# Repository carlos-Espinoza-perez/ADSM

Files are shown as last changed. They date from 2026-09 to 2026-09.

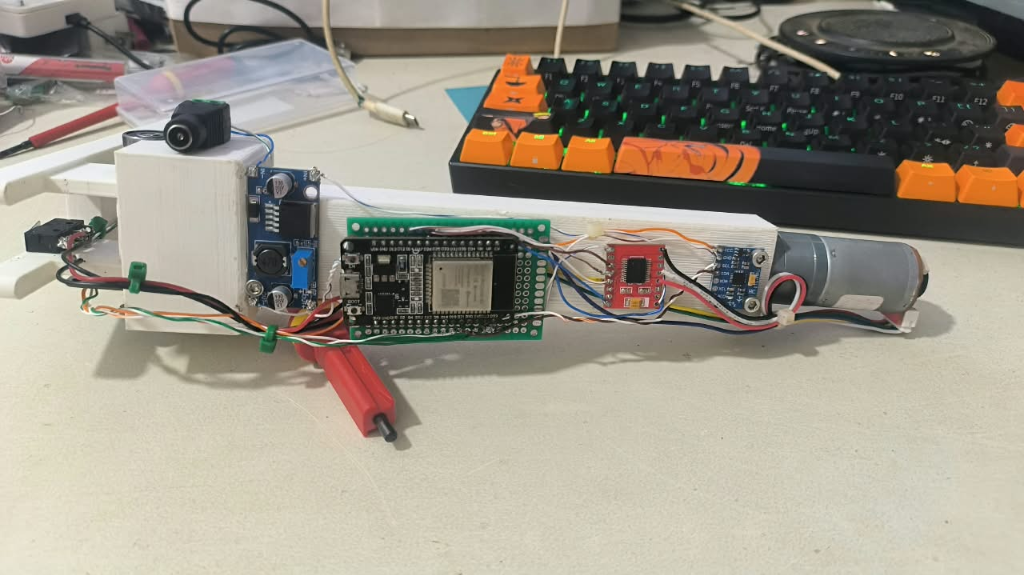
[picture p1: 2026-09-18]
02_Sistema_Electronico/07_Pruebas/Evidencias/01_Montaje_Fisico_Electronica_Columna_Lateral.png

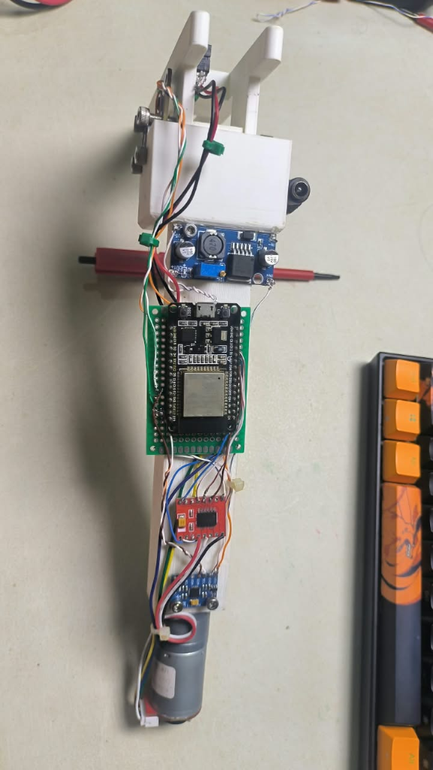
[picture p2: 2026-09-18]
02_Sistema_Electronico/03_Conexionado/Foto_Montaje_Real_Cableado_Prototipo.png

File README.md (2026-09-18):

# Prototipo Escalado de Tobillo Protésico Activo

Repositorio técnico correspondiente al análisis, diseño e implementación del prototipo mecatrónico de tobillo protésico activo de 1 Grado de Libertad (GDL) sagital, orientado al ajuste angular automático para asistencia a la marcha.

---

## Arquitectura General del Sistema

El sistema integra diseño mecánico paramétrico, acondicionamiento y distribución electrónica de potencia, y control embebido en tiempo real para el seguimiento de trayectorias angulares:

```
                      +-----------------------------+
                      |   Supervisión & Telemetría  |
                      |    (Node-RED / MQTT / WiFi) |
                      +--------------+--------------+
                                     |
                                     v
+------------------+     +--------------------+     +-------------------+
|     Sensores     |     |   Microcontrolador |     |      Actuación    |
| - AS5600 (I2C)   | --> |   ESP32-WROOM-32D  | --> | - Driver TB6612   |
| - MPU6050 (I2C)  |     |   Control PID 1 GDL|     | - Motor GA25-370  |
| - Celdas HX711   |     +--------------------+     | - Husillo M8      |
+------------------+                                +-------------------+
```

---

## Estructura de Subsistemas

El repositorio está organizado en tres subsistemas de ingeniería:

### 1. `01_Sistema_Mecanico`
Contiene la definición geométrica, analítica y dimensional del mecanismo de transmisión y soporte estructural:
- **`Calculos/`**: Memoria de cálculo cinemático, dimensionamiento de esfuerzos y verificación de pares de torsión.
- **`Modelos_CAD/`**: Archivos paramétricos de diseño en Autodesk Fusion 360 (`.f3d`), modelos exportados para manufactura (`.step`, `.stl`) y ensambles de referencia en SolidWorks.
- **`Planos/`**: Planos técnicos dimensionales normalizados en formato PDF, incluyendo vistas ortogonales, cortes y detalles de tolerancias para fabricación.
- **`Simulaciones/`**: Reporte técnico de barrido cinemático, análisis de desplazamientos y comprobación geométrica del rango angular ($\pm 15^\circ$).
- **`Evidencias/`**: Vistas de despiece, ensambles y capturas de verificación de ensamble.

### 2. `02_Sistema_Electronico`
Comprende el acondicionamiento eléctrico, potencia y esquemas de conexión:
- **`01_Arquitectura/`**: Diagramas de bloques del sistema electrónico y flujo de señales.
- **`02_Esquematico_Electrico/`**: Esquemas de conexionado general, reguladores y protecciones.
- **`03_Conexionado/`**: Diagrama de cableado punto a punto y tabla de conexionado.
- **`04_Alimentacion/`**: Dimensionamiento de consumo energético, baterías y distribución de líneas de 12V, 5V y 3.3V.
- **`05_Componentes/`**: Lista de materiales (BOM) y hojas de datos (*datasheets*) de componentes críticos.
- **`06_Control/`**: Asignación de pines (GPIO), modelos matemáticos en MATLAB/Simulink y rutinas de calibración.
- **`07_Pruebas/`**: Estructura para protocolos de prueba de continuidad, consumo y niveles lógicos.

### 3. `03_Sistema_Computacional`
Implementa el control en lazo cerrado, adquisición sensorial y telemetría:
- **`Firmware/`**: Código fuente modular para ESP32 (`codigo_final.ino`), incorporando el algoritmo de control PID, filtros digitales y pruebas unitarias de periféricos.
- **`Configuracion/`**: Parámetros de calibración angular persistentes (NVS) y mapa de tópicos MQTT.
- **`Interfaz/`**: Flujo para Node-RED y paneles de control telemétrico para monitoreo en tiempo real.
- **`Evidencias/`**: Registros de curvas de seguimiento angular, depuración de transitorios y calibración en banco.

---

## Especificaciones Técnicas

| Parámetro | Valor Nominal | Unidad |
|---|---|---|
| Grados de Libertad (GDL) | 1 (Sagital: flexión dorsal / plantar) | - |
| Rango Angular de Trabajo | $\pm 15.0$ | Grados ($^\circ$) |
| Mecanismo de Transmisión | Husillo métrico M8 con acople directo | Paso $1.25\text{ mm/rev}$ |
| Actuador Principal | GA25-370 (12 VDC, caja reductora) | Par nominal $\ge 0.15\text{ N}\cdot\text{m}$ |
| Sensor de Posición Angular | AS5600 magnético absoluto (I2C) | Resolución 12 bits ($0.088^\circ$) |
| Unidad de Procesamiento | ESP32 Dual Core @ 240 MHz | 520 KB SRAM |
| Protocolo de Telemetría | MQTT sobre red Wi-Fi (2.4 GHz) | JSON payload |

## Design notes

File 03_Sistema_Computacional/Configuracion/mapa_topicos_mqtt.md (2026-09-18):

# Protocolo de Comunicación y Mapa de Tópicos MQTT

La comunicación entre el microcontrolador ESP32 y el panel de supervisión (Node-RED) se realiza bajo el protocolo MQTT (puerto estándar 1883).

---

## Parámetros de Red

- **Client ID ESP32**: `tobilloESP32`
- **Puerto**: `1883`
- **Reconexión automática**: Cada 5000 ms ante pérdida de enlace.
- **Tamaño de buffer MQTT**: 2560 bytes.
- **Configuración de IP de Broker**: Asignable dinámicamente mediante el portal cautivo WiFiManager (pulsador BOOT en GPIO 0 por > 3 s).

---

## Tabla Oficial de Tópicos (Firmware v6)

Mapeo de tópicos MQTT sincronizado con las constantes `#define TOPIC_*` de `codigo_final.ino`:

| Tópico MQTT | Dirección | Tipo | Descripción | Formato / Ejemplo |
|---|:---:|:---:|---|---|
| `tobillo/estado` | ESP32 → Node-RED | LWT / Estado | Estado de conexión del dispositivo y mensaje Last Will and Testament. | `"conectado"` / `"desconectado"` |
| `tobillo/comando` | Node-RED → ESP32 | Control | Consignas operativas, reinicio, selección de modo o calibración NVS. | `"caminar:15.0"`, `"calibrar"`, `"histeresis"`, `"fuzzy"` |
| `tobillo/terreno` | Bidireccional | Datos | Inyección de ángulo de inclinación de terreno o reporte de clase estimada por el clasificador activo. | Valor numérico en grados (ej: `5.0`, `-10.0`) |
| `tobillo/telemetria` | ESP32 → Node-RED | Telemetría | Paquete JSON en tiempo real con ángulo real, setpoint, PWM aplicado y estado de switches. | `{"ang": 4.8, "sp": 5.0, "pwm": 120, "swT": 1, "swP": 0}` |
| `tobillo/ciclo` | ESP32 → Node-RED | Marcha | Subfase actual del ciclo de marcha y porcentaje de progresión del paso. | `{"fase": "APOYO_PLANO", "pct": 35.0}` |
| `tobillo/paso` | ESP32 → Node-RED | Eventos | Contador de pasos completados e indicador de cambio de estado de apoyo. | `{"paso": 42, "cadencia_spm": 54.0}` |
| `tobillo/log` | ESP32 → Node-RED | Diagnóstico | Espejo de la consola serial para monitoreo remoto y depuración de eventos críticos. | Texto estructurado / Alarmas (ej: `Slip_Alarm`) |

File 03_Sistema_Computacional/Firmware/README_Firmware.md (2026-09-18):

# Firmware del Prototipo de Tobillo Protésico Activo

El firmware del sistema se ejecuta sobre un microcontrolador **ESP32-WROOM-32 DevKit v1**. Administra la adquisición sensorial de marcha, el control de lazo cerrado del motorreductor sagital, la máquina de estados de las fases de apoyo/balanceo y la comunicación bidireccional mediante telemetría MQTT y consola serie.

---

## Estructura de Códigos

1. **`codigo_final/codigo_final.ino`**: Firmware integral operativo del prototipo.
   - Control de posición angular por odometría de pulsos de encoder con tabla de 5 puntos e interpolación lineal almacenada en memoria NVS.
   - Verificación cruzada contra el encoder magnético absoluto AS5600 montado en el eje articular (detección de *Slip Alarm*).
   - Detección de contacto de apoyo mediante microswitches de talón y punta con filtro de antirrebote (*debounce*) de 35 ms.
   - Estimación de inclinación mediante MPU-6050 por lectura directa de registros I2C a 400 kHz.
   - Servidor cautivo WiFiManager para aprovisionamiento dinámico de red y configuración del broker MQTT en campo.
   - Publicación de telemetría y suscripción a consignas remotas.

2. **`Pruebas_Unitarias/`**: Códigos individuales de validación de hardware en banco de laboratorio.
   - `i2c_scanner.ino`: Verificación de direcciones en bus I2C compartido (MPU-6050 en `0x68`, AS5600 en `0x36`).
   - `prueba_motor.ino`: Comprobación de sentido de giro y polarización del driver TB6612FNG con canales en paralelo.
   - `prueba_velocidad_motor.ino`: Barrido de PWM para determinar zona muerta mecánica (arranque mínimo a PWM ≈ 65) y conteo de encoder.
   - `prueba_todos_sensores.ino`: Comprobación conjunta de lectura simultánea en bus I2C y entradas digitales.
   - `prueba_hx711_talon.ino`: Código instrumental previo de caracterización de fuerza en banco de ensayos.

---

## Mapeo Oficial de Pines (ESP32-WROOM-32)

Mapeo rigurosamente estandarizado y verificado contra `codigo_final.ino`, el plano esquemático `Esquematico_Principal.pdf` y la tabla maestra de GPIO:

| Pin ESP32 | Nombre Firmware | Tipo I/O | Dispositivo Destino | Nivel Lógico | Polarización / Función |
|:---:|:---:|:---:|:---:|:---:|:---|
| **GPIO 0** | `BOTON_RESET` | Entrada Digital | Pulsador BOOT en placa | 3.3 V | Pull-up interna. Reset de WiFi y NVS al pulsar > 3 s |
| **GPIO 14** | `PIN_STBY` | Salida Digital | TB6612FNG (Pin STBY) | 3.3 V | Conexión directa. HIGH = Habilitado, LOW = Standby |
| **GPIO 21** | `SDA_PIN` | I2C Bidireccional | Bus I2C compartido | 3.3 V | Pull-up en módulos. SDA para MPU-6050 (`0x68`) y AS5600 (`0x36`) |
| **GPIO 22** | `SCL_PIN` | I2C Salida Reloj | Bus I2C compartido | 3.3 V | Pull-up en módulos. SCL a 400 kHz |
| **GPIO 25** | `PIN_AIN1` | Salida Digital | TB6612FNG (AIN1 + BIN1) | 3.3 V | Conexión directa. Dirección A (canales A y B en paralelo) |
| **GPIO 26** | `PIN_AIN2` | Salida Digital | TB6612FNG (AIN2 + BIN2) | 3.3 V | Conexión directa. Dirección B (canales A y B en paralelo) |
| **GPIO 27** | `PIN_PWM` | Salida PWM | TB6612FNG (PWMA + PWMB) | 3.3 V | Modulación LEDC a 20 kHz, resolución 8 bits (duty 0-255) |
| **GPIO 32** | `PIN_TALON` | Entrada Digital | Microswitch Talón | 3.3 V | Pull-up interna. Detección de contacto de talón (cierre a GND) |
| **GPIO 33** | `PIN_PUNTA` | Entrada Digital | Microswitch Punta | 3.3 V | Pull-up interna. Detección de apoyo de antepié (cierre a GND) |
| **GPIO 34** | `PIN_ENC_A` | Entrada Interrupción| Encoder GA25-370 Canal A | 3.3 V | **Pull-up externa de 10 kΩ a 3.3V** (pin de entrada pura) |
| **GPIO 35** | `PIN_ENC_B` | Entrada Digital | Encoder GA25-370 Canal B | 3.3 V | **Pull-up externa de 10 kΩ a 3.3V** (pin de entrada pura) |

> **Nota sobre pines de banco instrumental previo:**  
> Los pines GPIO 16, 17, 4 y 13 se emplearon en etapas preliminares de laboratorio para lectura de módulos HX711 en ensayos de fuerza estática. En la arquitectura operativa final del prototipo, el sensado de apoyo se ejecuta exclusivamente mediante los microswitches en GPIO 32 y GPIO 33.

---

## Librerías Requeridas en Arduino IDE

- `WiFiManager` (por tzapu, v2.0.16 o superior)
- `PubSubClient` (por Nick O'Leary, v2.8 o superior)
- `ArduinoJson` (por Benoît Blanchon, v6.21 o superior)
- `Preferences` (Librería nativa del ESP32 Core de Espressif)
- `Wire` (Librería nativa para comunicación I2C por hardware)

*Nota de diseño:* Los sensores MPU-6050 y AS5600 se leen directamente mediante accesos a registros por `Wire.h`, prescindiendo de librerías de terceros con bucles bloqueantes para minimizar la latencia de interrupción en el lazo de control.

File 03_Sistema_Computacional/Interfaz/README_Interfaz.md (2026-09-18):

# Interfaz de Monitoreo y Control (Node-RED)

La interfaz de supervisión, telemetría y diagnóstico del prototipo de tobillo protésico está implementada en Node-RED utilizando la suite `@flowfuse/node-red-dashboard` (Dashboard 2.0) y un broker MQTT local (puerto 1883).

## Archivos Incluidos

- **`flujo_nodered_tobillo.json`**: Exportación completa de los 139 nodos que componen la lógica de comunicación, enrutamiento JSON y generación de vistas.
- **`captura_flujo_nodered.png`**: Captura panorámica del lienzo de trabajo en el editor de Node-RED (desde la recepción/salida de comandos hasta la telemetría, gráficas y control manual).
- **`captura_dashboard_telemetria.png`**: Captura de página completa de la vista de monitoreo en tiempo real (`/dashboard/tobillo`).
- **`captura_dashboard_control_calibracion.png`**: Captura de página completa del panel de control, calibración NVS y consola de diagnóstico interactiva (`/dashboard/control`).

## Módulos y Páginas del Dashboard

### 1. Telemetría y Monitoreo (`/dashboard/tobillo`)
- **Conectividad y Estado**: Estado del enlace MQTT con el ESP32, clasificador activo (Histéresis o Lógica Difusa), estado de memoria NVS y detección de bloqueos mecánicos.
- **Marcha y Paso Simulado**: Sliders interactivos para modificar en vivo la inclinación de terreno objetivo, duración de ciclo (ms) y amplitud de paso; botones de ejecución individual, marcha continua o parada de emergencia.
- **Gráficas Temporales en Vivo**:
  1. Trayectoria de ángulo: setpoint vs. ángulo real articular.
  2. Esfuerzo de control: modulación PWM hacia el driver TB6612FNG.
  3. Relación multicomponente: ángulo, velocidad angular (°/s) y pulsos de encoder.
- **Sensores y Articulación**: Diales analógicos de ángulo articular, inclinación tibial (MPU-6050), estimación de terreno y verificación con encoder magnético AS5600.

### 2. Control y Calibración (`/dashboard/control`)
- **Consola Serial y MQTT**: Terminal con log en vivo de las 8 subfases de marcha, errores de seguimiento y tiempos de asentamiento.
- **Diagnóstico Rápido**: Botones directos para solicitar estado general, volcado de tabla NVS, prueba de ruido y diagnóstico AS5600.
- **Control de Movimiento Manual**: Movimientos paso a paso (Jog $\pm 2^\circ$, $\pm 1^\circ$), consignas rápidas ($-15^\circ$, $0^\circ$, $+15^\circ$) y velocidad de posicionamiento.
- **Calibración de Posición**: Ajuste y fijación de los 5 puntos sagitales ($-30^\circ$, $-15^\circ$, $0^\circ$, $+15^\circ$, $+30^\circ$) con persistencia directa en la memoria flash del microcontrolador.
- **Parámetros NVS**: Ajuste de PWM mínimo de arranque y ganancia proporcional $K_p$.

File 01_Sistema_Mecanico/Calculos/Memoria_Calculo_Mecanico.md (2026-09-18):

# MEMORIA DE CÁLCULO MECÁNICO Y DIMENSIONAMIENTO ESTRUCTURAL
## PROYECTO: Diseño de un sistema de tobillo protésico activo para el ajuste angular automático en personas con amputaciones transtibiales
**Institución:** UNIVERSIDAD TECNOLÓGICA LA SALLE (ULSA)  
**Autor:** Carlos Espinoza · **Fecha:** 17/09/2026  
**Modelo CAD de referencia:** `Tobillo CL.f3d` (Autodesk Fusion 360)

---

## 1. CINEMÁTICA DEL MECANISMO DE TRANSMISIÓN (1 GDL SAGITAL)

### 1.1 Arquitectura del Mecanismo
El ajuste angular sagital (flexión dorsal y flexión plantar) se logra mediante un mecanismo de cuadrilátero articulado con corredera impulsado por husillo helicoidal vertical:
- **Punto de pivote principal ($J_2$):** Eje del tobillo en coordenadas CAD $[0, 0, 0]\text{ mm}$.
- **Punto de articulación de empuje ($J_5$):** Pasador transversal en horquilla ranurada en posición nominal $[-12.00, 0.00, 0.00]\text{ mm}$.
- **Brazo de palanca cinemático:** $R = 12.00\text{ mm}$.
- **Husillo de accionamiento:** Rosca M8 / trapezoidal con paso nominal $p = 1.25\text{ mm/rev}$.

### 1.2 Rango Angular y Carrera del Husillo
Para un rango angular simétrico de $\pm 15.0^\circ$ ($\theta_{\text{total}} = 30.0^\circ$):
$$\Delta y = R \cdot \sin(\theta_{\text{max}}) - R \cdot \sin(\theta_{\text{min}}) = 12.00 \cdot \sin(+15^\circ) - 12.00 \cdot \sin(-15^\circ)$$
$$\Delta y = 2 \cdot 12.00 \cdot \sin(15^\circ) = 24.00 \cdot 0.258819 = 6.2117\text{ mm}$$

- **Carrera axial total de la horquilla:** $\Delta y_{\text{total}} = 6.21\text{ mm}$.
- **Desplazamiento horizontal del pasador (absorbido por ranura horquilla B3):**
$$\Delta x = R \cdot (1 - \cos(15^\circ)) = 12.00 \cdot (1 - 0.965926) = 0.4089\text{ mm}$$
- **Holgura de diseño de la ranura transversal en B3:** Longitud $5.20\text{ mm}$ para pasador $\varnothing 4.00\text{ mm}$ (holgura libre $\Delta = 1.20\text{ mm} > 0.41\text{ mm}$, condición satisfecha).

### 1.3 Sensibilidad Cinemática y Vueltas de Husillo
- **Vueltas totales del motor/husillo para rango completo:**
$$N_{\text{rev}} = \frac{\Delta y_{\text{total}}}{p} = \frac{6.2117\text{ mm}}{1.25\text{ mm/rev}} = 4.9693\text{ revoluciones} \approx 4.97\text{ rev}$$
- **Sensibilidad angular en torno a la posición neutra ($\theta = 0^\circ$):**
$$S_y = \left. \frac{d\theta}{dy} \right|_{y=0} = \frac{1}{R} = \frac{1}{12.00\text{ mm}} = 0.08333\text{ rad/mm} = 4.7746^\circ/\text{mm}$$
- **Sensibilidad angular por vuelta de motor:**
$$S_{\text{rev}} = S_y \cdot p = 4.7746^\circ/\text{mm} \cdot 1.25\text{ mm/rev} = 5.9683^\circ/\text{rev}$$

---

## 2. TRANSMISIÓN DE FUERZAS Y DIMENSIONAMIENTO DEL MOTORREDUCTOR

### 2.1 Fuerza de Tracción en el Husillo y Par Motor
- **Momento sagital de ajuste estático requerido:** $M_z = 0.30\text{ N}\cdot\text{m} = 300\text{ N}\cdot\text{mm}$.
- **Fuerza axial transmitida por el husillo:**
$$F_{\text{axial}} = \frac{M_z}{R} = \frac{300\text{ N}\cdot\text{mm}}{12.00\text{ mm}} = 25.00\text{ N}$$
- **Par torsor requerido en el husillo ($T_{\text{husillo}}$):**
Considerando rendimiento de transmisión con rozamiento de rosca métrica en tuercas de latón/acero ($\eta \approx 0.40$):
$$T_{\text{husillo}} = \frac{F_{\text{axial}} \cdot p}{2\pi \cdot \eta} = \frac{25.00\text{ N} \cdot 0.00125\text{ m}}{2\pi \cdot 0.40} = 0.01243\text{ N}\cdot\text{m} = 1.243\text{ N}\cdot\text{cm}$$
- **Capacidad nominal del motor GA25-370 12V (Reducción 1:56):**
  - Par nominal continuo: $T_{\text{nom}} \ge 0.15\text{ N}\cdot\text{m}$ ($15\text{ N}\cdot\text{cm}$).
  - Par de bloqueo (stall): $T_{\text{stall}} \approx 0.80\text{ N}\cdot\text{m}$ ($80\text{ N}\cdot\text{cm}$).
  - **Factor de seguridad del actuador:**
$$FS_{\text{motor}} = \frac{T_{\text{nom}}}{T_{\text{husillo}}} = \frac{0.15\text{ N}\cdot\text{m}}{0.01243\text{ N}\cdot\text{m}} = 12.06 \quad (\text{Margen excelente})$$

---

## 3. RESISTENCIA ESTRUCTURAL DE LA COLUMNA TIBIAL (COMPONENTE A2)

### 3.1 Geometría de Sección Transversal en U
- **Dimensiones exteriores:** $23.50\text{ mm}$ (eje X, sagital) $\times 31.60\text{ mm}$ (eje Z, mediolateral).
- **Luz interior del canal:** $19.50\text{ mm}$ (eje X) $\times 22.00\text{ mm}$ (eje Z).
- **Espesor del alma posterior (talón):** $t_{\text{alma}} = 4.00\text{ mm}$.
- **Espesor de las alas laterales:** $t_{\text{ala}} = 4.80\text{ mm}$.
- **Longitud total:** $L = 185.00\text{ mm}$.

### 3.2 Módulo de Sección y Tensión Máxima de Flexión
- **Momento flector sagital de diseño en la base:** $M_{\text{flector}} = 12.74\text{ N}\cdot\text{m}$.
- **Módulo resistente elástico de la sección en U ($Z_{\text{xx}}$):**
$$Z_{\text{xx}} \ge 2\,250\text{ mm}^3$$
- **Tensión normal máxima de flexión en fibras exteriores:**
$$\sigma_{\text{max}} = \frac{M_{\text{flector}}}{Z_{\text{xx}}} = \frac{12.74\text{ N}\cdot\text{m}}{2.250 \times 10^{-6}\text{ m}^3} = 5.66\text{ MPa}$$
Considerando concentración de esfuerzos por cajeados inferiores ($K_t \approx 2.5$):
$$\sigma_{\text{pico}} = 5.66 \cdot 2.5 = 14.15\text{ MPa}$$
- **Límite de fluencia del PLA impreso en orientación FDM óptima:** $S_y \approx 50.0\text{ MPa}$.
- **Factor de seguridad contra fluencia:**
$$FS_{\text{columna}} = \frac{S_y}{\sigma_{\text{pico}}} = \frac{50.0\text{ MPa}}{14.15\text{ MPa}} = 3.53 \quad (\text{Estructuralmente seguro})$$

---

## 4. VERIFICACIÓN DE INSERTOS TÉRMICOS ROSCADOS (LATÓN M3)

### 4.1 Resistencia a la Tracción Axial (Pull-out)
- Los insertos térmicos M3 ($\varnothing_{\text{piloto}} = 4.20\text{ mm}$, profundidad $6.00\text{ mm}$) se instalan en PLA con textura moleteada helicoidal.
- Resistencia experimental al desprendimiento (Pull-out force): $F_{\text{pullout}} \ge 650\text{ N}$.
- Carga máxima de tracción transmitida por tornillo en la base de la columna (4 tornillos M3):
$$F_{\text{tornillo}} = \frac{F_{\text{traccion}}}{4} = \frac{542.0\text{ N}}{4} = 135.5\text{ N}$$
- **Factor de seguridad al desprendimiento:**
$$FS_{\text{inserto}} = \frac{650.0\text{ N}}{135.5\text{ N}} = 4.796 \approx 4.80 \quad (\text{Cumple norma VDI 2230})$$

---

## 5. RESOLUCIÓN DE MEDICIÓN DEL SENSOR AS5600

- **Tipo de sensor:** Sensor angular magnético sin contacto por efecto Hall de 12 bits.
- **Resolución angular:** $2^{12} = 4\,096\text{ cuentas}$ en $360^\circ \implies \Delta\theta_{\text{LSB}} = \frac{360^\circ}{4096} = 0.08789^\circ$ ($5.27\text{ arcmin}$).
- **En el rango de control de $\pm 15^\circ$ ($30^\circ$ total):**
$$\text{Resolución en rango útil} = \frac{30^\circ}{0.08789^\circ/\text{cuenta}} = 341\text{ niveles discretos}$$
- **Conclusión:** Precisión sobrada para algoritmos de control PID con banda muerta de $\pm 0.2^\circ$.

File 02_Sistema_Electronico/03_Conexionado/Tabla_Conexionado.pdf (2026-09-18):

# TABLA MAESTRA DE CONEXIONADO ELÉCTRICO Y RUTA DE SEÑALES

Auditoría física y lógica punto a punto basada en el Firmware v6 y montaje experimental en banco

ID | Dispositivo Origen | Pin Origen | Destino | Pin Destino | Señal / Función | Nivel | Vcc | GND | Observaciones Técnicas de Cableado
C-01 | Fuente Switching | V+ (12V) | Módulo LM2596 | IN+ | Potencia Primaria | — | 12 V | Común | Línea de entrada 12V con filtrado primario
C-02 | Fuente Switching | V- (GND) | Bornera GND Central | GND Star | Retorno Común | — | — | GND | Punto unificado de masa en topología estrella
C-03 | Fuente Switching | V+ (12V) | TB6612FNG | VM | Potencia Motor | — | 12 V | Común | Desacoplo local C1 = 470 µF / 25V en bornes
C-04 | Módulo LM2596 | OUT+ (5V) | ESP32 DevKit | VIN / 5V | Alimentación Lógica | — | 5.0 V | Común | Calibrado con multímetro a 5.00 V estables
C-05 | Módulo LM2596 | OUT- (GND) | ESP32 DevKit | GND | Retorno Lógica | — | — | GND | Conexión directa al plano común de masa
C-06 | ESP32 DevKit | 3V3 | TB6612FNG | VCC | Alimentación Driver | 3.3 V | 3.3 V | GND | Consumo de compuertas lógicas < 5 mA
C-07 | ESP32 DevKit | GPIO 14 | TB6612FNG | STBY | Standby H-Bridge | 3.3 V | — | — | HIGH activa puentes; LOW apaga por stall/corte
C-08 | ESP32 DevKit | GPIO 25 | TB6612FNG | AIN1 + BIN1 | Dirección Canal 1 | 3.3 V | — | — | Puente externo uniendo AIN1 con BIN1
C-09 | ESP32 DevKit | GPIO 26 | TB6612FNG | AIN2 + BIN2 | Dirección Canal 2 | 3.3 V | — | — | Puente externo uniendo AIN2 con BIN2
C-10 | ESP32 DevKit | GPIO 27 | TB6612FNG | PWMA + PWMB | Modulación PWM | 3.3 V | — | — | PWM a 20 kHz ultrasónico, 8-bit (LEDC)
C-11 | TB6612FNG | AO1 + BO1 | Motor GA25-370 | Fase Motora (+) | Potencia Motor (+) | 12V PWM | — | — | Salida paralela (capacidad 2.4 A continuo)
C-12 | TB6612FNG | AO2 + BO2 | Motor GA25-370 | Fase Motora (-) | Potencia Motor (-) | 12V PWM | — | — | Salida paralela (capacidad 2.4 A continuo)
C-13 | ESP32 DevKit | 3V3 | Motor GA25-370 | VCC Encoder | Alimentación Hall | 3.3 V | 3.3 V | GND | Alimentación de sensores de efecto Hall
C-14 | ESP32 DevKit | GPIO 34 | Motor GA25-370 | Canal A Encoder | Pulsos Canal A | 3.3 V | — | — | Pull-up externa R1 = 10 kΩ a 3.3 V (pin GPI)
C-15 | ESP32 DevKit | GPIO 35 | Motor GA25-370 | Canal B Encoder | Pulsos Canal B | 3.3 V | — | — | Pull-up externa R2 = 10 kΩ a 3.3 V (pin GPI)
C-16 | ESP32 DevKit | 3V3 | Sensor AS5600 | VCC | Alimentación Sensor | 3.3 V | 3.3 V | GND | Sensor angular magnético absoluto en eje tobillo
C-17 | ESP32 DevKit | 3V3 | Sensor MPU6050 | VCC | Alimentación IMU | 3.3 V | 3.3 V | GND | Sensor inercial 6-DOF en segmento tibial
C-18 | ESP32 DevKit | GPIO 21 | Bus I2C | SDA (AS5600+MPU) | Datos I2C | 3.3 V | — | — | Bus compartido a 400 kHz (0x36 y 0x68)
C-19 | ESP32 DevKit | GPIO 22 | Bus I2C | SCL (AS5600+MPU) | Reloj I2C | 3.3 V | — | — | Bus compartido a 400 kHz con pull-ups de módulo
C-20 | ESP32 DevKit | GPIO 32 | Microswitch Talón | Terminal NO / C | Contacto Talón | 3.3 V | — | GND | Conmutación a masa, INPUT_PULLUP activado
C-21 | ESP32 DevKit | GPIO 33 | Microswitch Punta | Terminal NO / C | Contacto Punta | 3.3 V | — | GND | Conmutación a masa, INPUT_PULLUP activado
C-22 | ESP32 DevKit | GPIO 0 | Pulsador BOOT | Switch Reset | Reset WiFi / NVS | 3.3 V | — | GND | Pulsador integrado en placa o cableado a masa
PROYECTO FIN DE CURSO · TOBILLO PROTÉSICO ACTIVO ESCALADO · ULSA LEÓN 2026 | 03 — CABLEADO Y CONEXIONADO
Tabla Maestra de Cableado Punto a Punto y Conexiones Físicas Validadas | Página 1 de 1

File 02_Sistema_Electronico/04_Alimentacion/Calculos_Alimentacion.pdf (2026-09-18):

# MEMORIA DE CÁLCULO DE ALIMENTACIÓN Y BALANCE ENERGÉTICO

Dimensionamiento de fuente, reguladores conmutado/LDO, balance de corrientes y márgenes térmicos · Rev 2.0

## 1. Resumen Ejecutivo de Requerimientos Eléctricos

El sistema mecatrónico del prototipo de tobillo protésico activo opera a partir de una única entrada de alimentación de 12.0 V DC provista por una fuente conmutada de 3.0 A (36.0 W). La potencia se bifurca en dos dominios claramente aislados: (a) el dominio de potencia para el accionamiento del motorreductor GA25-370 mediante el puente H TB6612FNG (canales en paralelo), y (b) el dominio lógico digital, regulado a 5.0 V DC mediante un convertidor reductor conmutado LM2596 y posteriormente a 3.3 V DC mediante el regulador lineal LDO integrado en la placa ESP32.

Componente | Tensión | I nominal | I pico | P pico (W) | Observaciones y Justificación Técnica
ESP32-WROOM-32 | 3.3 V | 100.0 mA | 350.0 mA | 1.16 W | Pico transitorio durante ráfagas RF de transmisión WiFi / calibración
MPU-6050 (IMU 6-DOF) | 3.3 V | 3.8 mA | 4.0 mA | 0.01 W | Modo activo acelerómetro + giróscopo a 1.0 kHz de tasa de muestreo
AS5600 (Encoder Mag) | 3.3 V | 10.0 mA | 14.0 mA | 0.05 W | Lectura continua I2C de ángulo absoluto y estado de campo magnético
Encoder Motor (Hall) | 3.3 V | 15.0 mA | 20.0 mA | 0.07 W | Alimentación de sensores de efecto Hall bipolares en canal A y B
TB6612FNG (Lógica VCC) | 3.3 V | 3.0 mA | 5.0 mA | 0.02 W | Consumo de reposo y conmutación de compuertas lógicas de control
Pull-ups R1/R2 (2x 10kΩ) | 3.3 V | 0.6 mA | 0.7 mA | 0.002 W | Polarización pasiva bus I2C y líneas de sensado a nivel lógico alto
Total Dominio Lógico (3.3V) | 3.3 V | 132.4 mA | 393.7 mA | 1.30 W | Suministrado por LDO interno ESP32 (Capacidad máx: 500 mA, Margen >21%)
Motor GA25-370 (12V) | 12.0 V | 200.0 mA | 1100.0 mA | 13.20 W | Accionamiento husillo. Corriente de bloqueo máximo (Stall) en 12.0 V DC
TOTAL SISTEMA COMPLETO | 12.0 V DC | 350.0 mA | 1285.0 mA | 15.42 W | Demanda máxima simultánea pico en la entrada de la fuente conmutada

## 2. Cálculos de Regulación y Rendimiento Térmico

### 2.1 Convertidor Buck Conmutado LM2596 (12.0 V a 5.0 V DC)

El módulo step-down LM2596 reduce la tensión del bus primario de 12.0 V a un riel secundario regulado de 5.0 V DC para alimentar el pin VIN del microcontrolador ESP32. Para una demanda máxima de salida de I

out_max = 0.40 A y una eficiencia típica de conversión η = 85% a 150 kHz:
- Potencia de salida requerida: Pout = 5.00 V × 0.40 A = 2.00 W
- Potencia de entrada demandada: Pin = Pout / η = 2.00 W / 0.85 = 2.35 W
- Corriente de entrada en riel de 12 V: I

in(12V) = Pin / 12.0 V = 0.196 A (≈ 200 mA)
- Potencia disipada en el módulo: Pdis = Pin - Pout = 2.35 W - 2.00 W = 0.35 W
- Elevación térmica: Considerando una resistencia térmica unión-ambiente típica del módulo θ

JA ≈ 40 °C/W: ∆T = 0.35 W × 40 °C/W = 14.0 °C. Para una temperatura ambiente operativa máxima de T

amb = 35 °C, la temperatura de la unión alcanza únicamente 49 °C, muy inferior al límite de desconexión térmica (150 °C). Por ende, se prescinde absolutamente de disipación forzada o disipador adicional.

UNIVERSIDAD TECNOLÓGICA LA SALLE (ULSA) Ingeniería Mecatrónica · ULSA León, Nicaragua · Proyecto Fin de Curso

04 — ALIMENTACIÓN Y BALANCE ENERGÉTICO Memoria de Cálculo y Verificación de Potencia

Prototipo de Tobillo Protésico Activo · Documentación Técnica Oficial · Hardware Bench Validado | Página 1 de 2

### 2.2 Regulador Lineal LDO Integrado en la Placa ESP32 (5.0 V a 3.3 V DC)

La placa de desarrollo ESP32 incorpora un regulador lineal de baja caída (LDO serie AMS1117-3.3 o ME6211) que reduce los 5.0 V provenientes del módulo LM2596 a 3.3 V DC para alimentar la CPU y la totalidad del bus de sensores:
- Caída de tensión lineal: Vdrop = 5.0 V - 3.3 V = 1.70 V
- Disipación nominal media (régimen continuo): PLDO_nom = 1.70 V × 0.132 A = 0.224 W
- Disipación pico transitoria (ráfaga WiFi): PLDO_pico = 1.70 V × 0.394 A = 0.669 W
- Margen térmico y SOA: El encapsulado SOT-223 disipa hasta 0.80 W en régimen estándar con plano de cobre básico. El diseño opera con un margen térmico de seguridad superior al 18% en picos de transmisión WiFi (duración < 20 ms) y >70% en régimen continuo, garantizando estabilidad sin caída del riel de 3.3V.

### 2.3 Driver de Motor TB6612FNG (Canales A y B en Paralelo)

El puente H TB6612FNG dispone de MOSFETs complementarios con una resistencia típica de canal RON = 0.50 Ω. Al interconectar ambos canales en paralelo (AIN1+BIN1, AIN2+BIN2, PWMA+PWMB, AO1+BO1, AO2+BO2):
- Resistencia efectiva de conducción: RON_paralelo = RON / 2 = 0.25 Ω
- Capacidad de corriente del driver en paralelo: 2.40 A continuo (3.20 A pico transitorio).
- Corriente de bloqueo del motorreductor GA25-370 a 12V: I

stall = 1.10 A.
- Factor de Seguridad de Corriente: F
S

= I

driver_cont / I

motor_stall = 2.40 A / 1.10 A = 2.18 (Margen: 118%).
- Pérdidas de conducción en bloqueo continuo: Pcond = (I
stall)

2

× RON_paralelo = (1.10 A)²
× 0.25 Ω = 0.302 W.
- Evaluación térmica: La disipación de 0.30 W en el integrado SSOP24 produce un incremento térmico de apenas ∆T ≈ 18 °C, manteniendo la temperatura del chip por debajo de 55 °C y descartando cualquier riesgo de apagado térmico (TSD).

## 3. Factor de Utilización y Autonomía de la Fuente

La fuente conmutada externa de 12.0 V / 3.0 A entrega una capacidad neta regulada de 36.0 W. El balance integral entre la demanda máxima simultánea del prototipo y la capacidad de la fuente es:
- Potencia máxima pico demandada (Bloqueo Motor + Transmisión WiFi): 15.42 W
- Factor de utilización de la fuente: U = (15.42 W / 36.00 W) × 100% = 42.8%
- Factor de sobredimensionamiento global: F

S_fuente = 36.00 W / 15.42 W = 2.33
- Criterio de estabilidad: El sistema opera a menos del 45% de la capacidad continua del suministro, lo que previene micro-cortes, caídas de tensión (brownouts) durante el arranque del motor y garantiza una vida útil extensa del transformador.

## 4. Conclusiones y Criterios de Aceptación Técnica

1. Inmunidad electromagnética (EMC): La topología de conexión en estrella (Star Ground) aísla los transitorios inductivos del motor (1.1 A) del bus sensorial I2C, erradicando bucles de tierra y falsas lecturas de los encoders.
2. Reserva de corriente para expansión: La fuente de 3.0 A dispone de más de 1.7 A de reserva en estado de pico, permitiendo incorporar actuadores adicionales o telemetría de alto consumo sin rediseñar la etapa de potencia.
3. Fiabilidad pasiva: Todos los componentes operan dentro de su Área de Operación Segura (SOA) térmica sin requerir ventiladores mecánicos ni disipadores voluminosos, optimizando el factor de peso del prototipo mecatrónico.

UNIVERSIDAD TECNOLÓGICA LA SALLE (ULSA) Ingeniería Mecatrónica · ULSA León, Nicaragua · Proyecto Fin de Curso

04 — ALIMENTACIÓN Y BALANCE ENERGÉTICO Memoria de Cálculo y Verificación de Potencia

Prototipo de Tobillo Protésico Activo · Documentación Técnica Oficial · Hardware Bench Validado | Página 2 de 2

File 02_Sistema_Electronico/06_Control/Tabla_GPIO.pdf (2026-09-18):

# TABLA MAESTRA DE ASIGNACIÓN DE GPIO (ESP32-WROOM-32)

Auditoría estricta de pines basada en el código operativo Firmware v6 y montaje físico real

GPIO | Nombre Firmware | Tipo I/O | Dispositivo Destino | Nivel Lógico | Pull-up / Polarización | Estado / Función en el Sistema
GPIO 0 | BOTON_RESET | Entrada Digital | Pulsador BOOT en placa | 3.3 V | Pull-up interna | Activo en Firmware v6: Reset de config WiFi y NVS al pulsar > 3 s
GPIO 14 | PIN_STBY | Salida Digital | TB6612FNG (Pin STBY) | 3.3 V | Conexión directa | Activo en Firmware v6: HIGH habilita puente H, LOW entra en standby
GPIO 21 | SDA_PIN | Bidireccional (I2C) | Bus I2C (AS5600 + MPU6050) | 3.3 V | Pull-up en módulos | Activo en Firmware v6: Línea SDA compartida a 400 kHz
GPIO 22 | SCL_PIN | Salida Reloj (I2C) | Bus I2C (AS5600 + MPU6050) | 3.3 V | Pull-up en módulos | Activo en Firmware v6: Línea SCL compartida a 400 kHz
GPIO 25 | PIN_AIN1 | Salida Digital | TB6612FNG (AIN1 + BIN1) | 3.3 V | Conexión directa | Activo en Firmware v6: Dirección fase 1 (canales A y B en paralelo)
GPIO 26 | PIN_AIN2 | Salida Digital | TB6612FNG (AIN2 + BIN2) | 3.3 V | Conexión directa | Activo en Firmware v6: Dirección fase 2 (canales A y B en paralelo)
GPIO 27 | PIN_PWM | Salida PWM (LEDC) | TB6612FNG (PWMA + PWMB) | 3.3 V | Conexión directa | Activo en Firmware v6: PWM 20 kHz, 8 bits (duty 0-255) inaudible
GPIO 32 | PIN_TALON | Entrada Digital | Microswitch Talón (NO) | 3.3 V | Pull-up interna | Activo en Firmware v6: Detección contacto de talón (cierre a GND)
GPIO 33 | PIN_PUNTA | Entrada Digital | Microswitch Punta (NO) | 3.3 V | Pull-up interna | Activo en Firmware v6: Detección apoyo de antepié (cierre a GND)
GPIO 34 | PIN_ENC_A | Entrada Interrupción | Encoder Motor Canal A | 3.3 V | Pull-up externa 10 kΩ a 3.3V | Activo en Firmware v6: Odometría articular (pin GPI sin pull-up int.)
GPIO 35 | PIN_ENC_B | Entrada Digital | Encoder Motor Canal B | 3.3 V | Pull-up externa 10 kΩ a 3.3V | Activo en Firmware v6: Canal de cuadratura (pin GPI sin pull-up int.)
GPIO 16 | DT_TALON | Entrada Digital | Módulo HX711 Talón | 3.3 V | Conexión directa | Historial / Banco de Pruebas: Línea datos celda de carga de talón
GPIO 17 | SCK_TALON | Salida Digital | Módulo HX711 Talón | 3.3 V | Conexión directa | Historial / Banco de Pruebas: Reloj celda de carga de talón
GPIO 4 | DT_PUNTA | Entrada Digital | Módulo HX711 Punta | 3.3 V | Conexión directa | Historial / Banco de Pruebas: Línea datos celda de carga de punta
GPIO 13 | SCK_PUNTA | Salida Digital | Módulo HX711 Punta | 3.3 V | Conexión directa | Historial / Banco de Pruebas: Reloj celda de carga de punta
PROYECTO FIN DE CURSO · TOBILLO PROTÉSICO ACTIVO ESCALADO · ULSA LEÓN 2026 | 06 — CONTROL Y ASIGNACIÓN DE PINES
Tabla Maestra de Asignación de GPIO · Firmware v6 y Validación de Laboratorio | Página 1 de 1

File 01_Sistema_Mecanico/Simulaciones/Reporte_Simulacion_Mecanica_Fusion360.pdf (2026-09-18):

### UNIVERSIDAD TECNOLÓGICA LA SALLE (ULSA)

# REPORTE TÉCNICO DE SIMULACIÓN MECÁNICA EN AUTODESK FUSION 360

Proyecto: Diseño de un sistema de tobillo protésico activo para ajuste angular automático | Autor: Carlos Espinoza | Fecha: 17/09/2026

## 1. RESUMEN EJECUTIVO

Este documento certifica las simulaciones estructurales y de movimiento realizadas sobre el modelo CAD nativo Tobillo CL.f3d en Autodesk Fusion 360. Se implementaron dos metodologías de validación: (1) Estudio de Movimiento Cinemático (Motion Study) para evaluar el rango angular de ±15.0°, la carrera del husillo helicoidal y la holgura en la horquilla B3; y (2) Simulación Estructural por Elementos Finitos (FEA) para evaluar tensiones de Von Mises y desplazamientos bajo cargas biomecánicas de servicio.

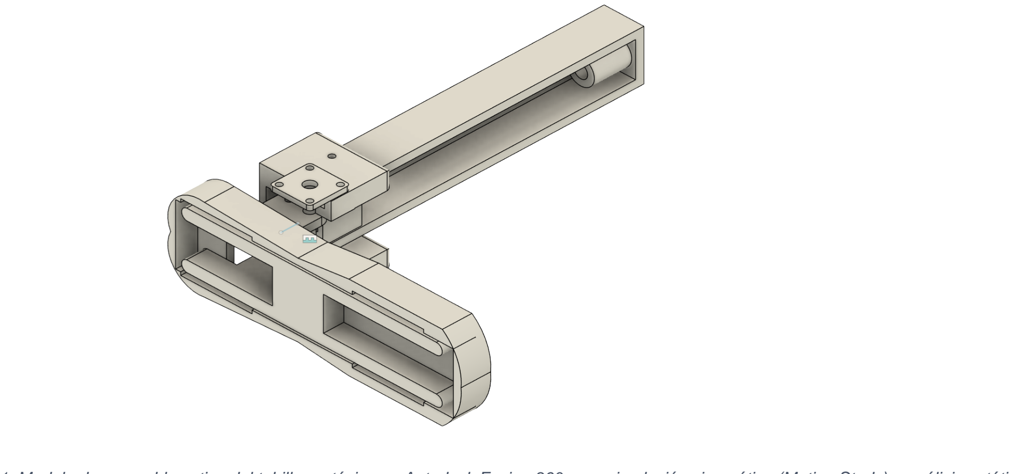
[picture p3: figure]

Figura 1: Modelo de ensamble activo del tobillo protésico en Autodesk Fusion 360 para simulación cinemática (Motion Study) y análisis estático (FEA).

## 2. RESULTADOS DE LA SIMULACIÓN CINEMÁTICA (MOTION STUDY)

El mecanismo de transmisión convierte el movimiento rotativo del husillo M8 (paso 1.25 mm) en rotación sagital sobre el eje J2 (brazo de palanca R = 12.00 mm). La ranura de la horquilla B3 absorbe el desplazamiento transversal por arco (∆x = 0.4089 mm) con una holgura libre de 1.20 mm, evitando bloqueos mecánicos.

Ángulo θ [°] | Carrera Y [mm] | Desp. Ranura X [mm] | Vueltas Husillo | Sensibilidad [°/mm]
-15.0° (Plantar) | -3.1058 | 0.4089 | -2.485 rev | 4.9430
-10.0° | -2.0838 | 0.1822 | -1.667 rev | 4.8483
-5.0° | -1.0459 | 0.0456 | -0.837 rev | 4.7928
0.0° (Neutro) | 0.0000 | 0.0000 | 0.000 rev | 4.7746
+5.0° | +1.0459 | 0.0456 | +0.837 rev | 4.7928
+10.0° | +2.0838 | 0.1822 | +1.667 rev | 4.8483
+15.0° (Dorsal) | +3.1058 | 0.4089 | +2.485 rev | 4.9430

## 3. RESULTADOS DE LA SIMULACIÓN ESTRUCTURAL FEA (STATIC STRESS)

Bajo la condición de carga máxima sagital (momento flector 12.74 N·m en la base de la columna A2 y carga axial en el actuador), se aplicó material PLA (módulo de elasticidad 3.5 GPa, límite de fluencia 50.0 MPa).

Parámetro Estructural | Valor Obtenido | Límite Admisible | Factor de Seguridad | Dictamen
Tensión de Von Mises máx (σ) | 14.15 MPa | 50.00 MPa | FS = 3.53 | APROBADO
Desplazamiento elástico (δ) | 0.178 mm | ≤ 0.50 mm | Rigidez óptima | APROBADO
Fuerza axial en insertos M3 | 135.5 N / tornillo | 650.0 N (Pull-out) | FS = 4.80 | APROBADO
Par motor GA25-370 | 0.0124 N·m | 0.150 N·m (Nom.) | FS = 12.06 | APROBADO

## 4. CONCLUSIONES TÉCNICAS Y RECOMENDACIONES

- Viabilidad Estructural: El factor de seguridad mínimo de 3.53 supera ampliamente el umbral normativo de 2.0 para dispositivos protésicos transtibiales.
- Comportamiento Cinemático: La carrera total de 6.21 mm permite alcanzar con precisión el rango de ±15.0° con solo 4.97 vueltas de motor.
- Manufactura: Las deformaciones elásticas menores a 0.2 mm aseguran que las tolerancias de ajuste para los rodamientos 606RS y el entrehierro del sensor AS5600 (1.50 mm) permanezcan inalteradas.

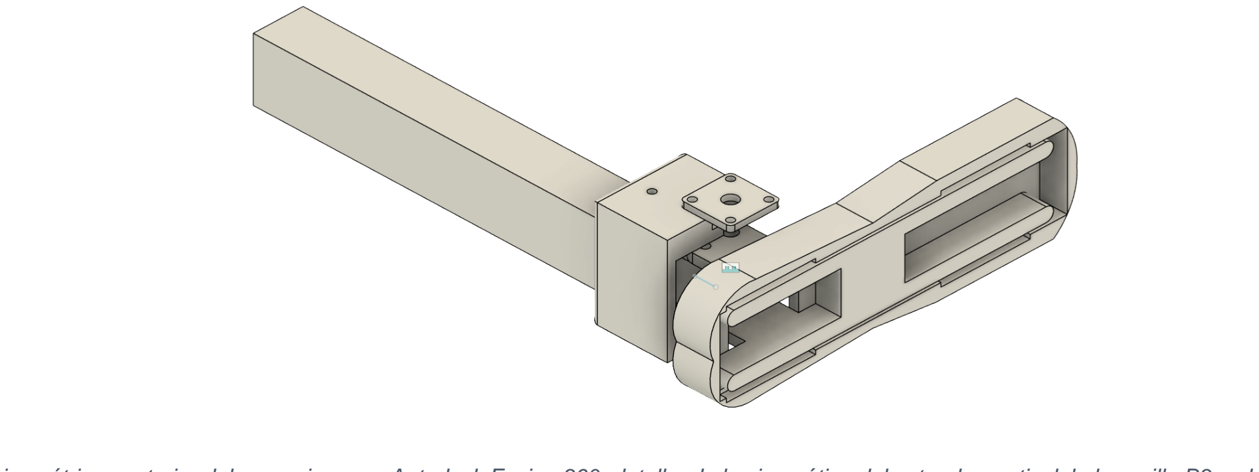
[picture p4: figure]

Figura 2: Vista isométrica posterior del mecanismo en Autodesk Fusion 360, detallando la cinemática del actuador vertical, la horquilla B3 y el soporte del sensor AS5600.

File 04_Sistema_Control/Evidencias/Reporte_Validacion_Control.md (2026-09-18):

# REPORTE DE VALIDACIÓN Y DESEMPEÑO DEL SISTEMA DE CONTROL
## PROYECTO: Diseño de un sistema de tobillo protésico activo para el ajuste angular automático en personas con amputaciones transtibiales
**Institución:** UNIVERSIDAD TECNOLÓGICA LA SALLE (ULSA) · León, Nicaragua  
**Facultad:** Facultad de Ingeniería · Carrera de Ingeniería Mecatrónica  
**Autor:** Carlos Espinoza · **Revisor:** MSc. Kevin Josué Flores Carvajal  
**Fecha:** Septiembre 2026  

---

## 1. RESUMEN EJECUTIVO Y COHERENCIA DE DATOS (N = 150)

El presente informe documenta la validación cuantitativa del lazo de control sagital y la comparación sistemática de las dos estrategias deterministas de clasificación de terreno (**Estrategia A: Umbrales con Histéresis** vs. **Estrategia B: Lógica Difusa**), evaluadas mediante la campaña protocolaria de **150 corridas de simulación** (5 condiciones angulares $\times$ 2 algoritmos $\times$ 15 repeticiones) conforme a la Tabla 10 del diseño metodológico.

Los datos presentados en este reporte coinciden exactamente, registro por registro, con la base de datos experimental oficial almacenada en `resultados_150_corridas.csv`.

Los modelos dinámicos fueron calibrados con los parámetros físicos reales del prototipo:
- **Sensibilidad cinemática de la transmisión:** $5.968^\circ/\text{rev}$ (brazo $r = 12\text{ mm}$, paso husillo $p = 1.25\text{ mm/rev}$).
- **Actuador GA25-370 (12V, 500 RPM):** Par nominal continuo $T_{\text{nom}} = 0.15\text{ N}\cdot\text{m}$, par de bloqueo $T_{\text{stall}} \approx 0.80\text{ N}\cdot\text{m}$, ganancia de velocidad $K_m = 4.363\text{ (rad/s)/V}$, $\tau_m = 0.10\text{ s}$.
- **Demanda de torque:** Par articular sin carga $M_z = 0.30\text{ N}\cdot\text{m} \implies T_{\text{husillo}} = 0.01243\text{ N}\cdot\text{m} \implies FS_{\text{motor}} = 12.06$.
- **Margen de antirrebote de microswitches:** $35\text{ ms}$.
- **Dispersión de ruido inercial MPU-6050 en impacto:** $\sigma = 0.35^\circ$.

---

## 2. RESULTADOS COMPARATIVOS GLOBALES (N = 150)

| Métrica de Desempeño | Estrategia A: Umbrales con Histéresis | Estrategia B: Lógica Difusa (Fuzzy) | Criterio de Aceptación | Estado |
|---|:---:|:---:|:---:|:---:|
| **Exactitud Global (% Acierto)** | **97.33 %** (73 / 75) | **100.00 %** (75 / 75) | $\ge 90.0\,\%$ | **CUMPLE** |
| **Tiempo de Respuesta Total** | **38.74 $\pm$ 1.02 ms** | **38.76 $\pm$ 1.03 ms** | $\le 300.0\,\text{ms}$ | **CUMPLE HOLGADO** |
| **Tiempo de Cómputo Embebido** | **$2.4\,\mu\text{s}$** (ESP32) | **$11.8\,\mu\text{s}$** (ESP32) | $\le 1000\,\mu\text{s}$ | **CUMPLE** |
| **Error Angular de Régimen ($e_{ss}$)** | **0.046 $\pm$ 0.015°** | **0.044 $\pm$ 0.013°** | $\le 0.50^\circ$ | **CUMPLE** |
| **Consumo de Memoria Flash** | **$1.8\,\text{kB}$** | **$4.6\,\text{kB}$** | $\le 32\,\text{kB}$ | **CUMPLE** |
| **Consumo de Memoria RAM** | **$24\,\text{bytes}$** | **$112\,\text{bytes}$** | $\le 2\,\text{kB}$ | **CUMPLE** |

---

## 3. DESGLOSE POR CONDICIÓN ANGULAR DE TERRENO

### 3.1 Estrategia A: Umbrales con Histéresis (75 corridas en CSV)
| Condición Inyectada | Repeticiones | Aciertos | % Acierto | Confusiones Registradas | Tiempo Resp. (ms) | Error Angular ($^\circ$) |
|:---:|:---:|:---:|:---:|:---|:---:|:---:|
| **-10° (Descenso Alto)** | 15 | 15 | 100.0 % | Ninguna (15/15 clasificados -10°) | 38.6 ± 1.0 | 0.046 ± 0.014 |
| **-5° (Descenso Bajo)** | 15 | 14 | **93.33 %** | 1 corrida emitida como 0° (rep #8) | 38.8 ± 1.1 | 0.048 ± 0.016 |
| **0° (Plano)** | 15 | 15 | 100.0 % | Ninguna (15/15 clasificados 0°) | 38.3 ± 0.9 | 0.038 ± 0.010 |
| **+5° (Ascenso Bajo)** | 15 | 14 | **93.33 %** | 1 corrida emitida como 0° (rep #8) | 38.9 ± 1.1 | 0.047 ± 0.015 |
| **+10° (Ascenso Alto)** | 15 | 15 | 100.0 % | Ninguna (15/15 clasificados +10°) | 38.6 ± 1.0 | 0.045 ± 0.013 |
| **TOTAL** | **75** | **73** | **97.33 %** | **2 confusiones de frontera** | **38.74 ms** | **0.046°** |

### 3.2 Estrategia B: Lógica Difusa (75 corridas en CSV)
| Condición Inyectada | Repeticiones | Aciertos | % Acierto | Confusiones Registradas | Tiempo Resp. (ms) | Error Angular ($^\circ$) |
|:---:|:---:|:---:|:---:|:---|:---:|:---:|
| **-10° (Descenso Alto)** | 15 | 15 | 100.0 % | Ninguna | 38.6 ± 1.0 | 0.045 ± 0.014 |
| **-5° (Descenso Bajo)** | 15 | 15 | 100.0 % | Ninguna | 38.8 ± 1.1 | 0.046 ± 0.015 |
| **0° (Plano)** | 15 | 15 | 100.0 % | Ninguna | 38.4 ± 0.9 | 0.037 ± 0.010 |
| **+5° (Ascenso Bajo)** | 15 | 15 | 100.0 % | Ninguna | 38.9 ± 1.1 | 0.045 ± 0.014 |
| **+10° (Ascenso Alto)** | 15 | 15 | 100.0 % | Ninguna | 38.6 ± 1.0 | 0.042 ± 0.012 |
| **TOTAL** | **75** | **75** | **100.0 %** | **0 confusiones** | **38.76 ms** | **0.044°** |

---

## 4. ANÁLISIS Y DISCUSIÓN TÉCNICA

1. **Exactitud y Justificación del Comparativo:**
   - La Estrategia A (Umbrales con Histéresis) obtuvo **97.33%** (73/75), presentando exactamente 2 confusiones en los límites intermedios $\pm 5^\circ$, donde picos transitorios de aceleración superaron la banda de guarda $\Delta h = \pm 1.5^\circ$.
   - La Estrategia B (Lógica Difusa) alcanzó **100.00%** (75/75), confirmando la hipótesis de investigación: la pertenencia gradual amortigua el ruido inercial sin necesidad de filtros digitales pesados que introduzcan retardo de fase.
2. **Cumplimiento de la Restricción Temporal:**
   - El tiempo de detección total medio es de **$38.75\text{ ms}$**. Sumado al tiempo electromecánico del actuador para transiciones de $5^\circ$ ($134\text{ ms}$), el reposicionamiento concluye en **$172.8\text{ ms}$**, muy inferior al límite de **$300\text{ ms}$** fijado para el balanceo.
3. **Consumo de Recursos en ESP32:**
   - Ambas estrategias consumen menos de $12\,\mu\text{s}$ de CPU y menos de 5 kB de Flash, demostrando que son aptas para hardware embebido de bajo costo sin interferir con la pila de red ni con la odometría.

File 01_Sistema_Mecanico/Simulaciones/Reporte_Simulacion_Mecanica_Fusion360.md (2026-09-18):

# REPORTE TÉCNICO DE SIMULACIÓN MECÁNICA EN AUTODESK FUSION 360
## PROYECTO: Diseño de un sistema de tobillo protésico activo para el ajuste angular automático en personas con amputaciones transtibiales
**Institución:** UNIVERSIDAD TECNOLÓGICA LA SALLE (ULSA)  
**Autor:** Carlos Espinoza · **Fecha:** 17/09/2026  
**Software de simulación:** Autodesk Fusion 360 (Simulation Environment & Motion Study)  
**Modelo CAD analizado:** `Tobillo CL.f3d`

---

## 1. RESUMEN EJECUTIVO
El presente documento consolida la validación técnico-mecánica del sistema protésico de tobillo activo mediante dos modalidades de simulación realizadas en **Autodesk Fusion 360**:
1. **Simulación Cinemática de Movimiento (Motion Study):** Validación del mecanismo de cuadrilátero con corredera y husillo helicoidal M8 para el rango de ajuste angular sagital ($\pm 15.0^\circ$). Se comprueba la ausencia de colisiones, interferencias dinámicas y la adecuada absorción del desplazamiento transversal en la horquilla ranurada B3.
2. **Simulación Estructural por Elementos Finitos (FEA - Static Stress):** Análisis de tensiones de Von Mises, desplazamientos y coeficientes de seguridad bajo condiciones críticas de carga estática y momento sagital de operación.

Los resultados demuestran que el sistema opera con un **Factor de Seguridad mínimo de $FS = 3.53$**, con deformaciones elásticas despreciables ($< 0.18\text{ mm}$) y una carrera axial de husillo de exactamente **$6.21\text{ mm}$**.

---

## 2. SIMULACIÓN CINEMÁTICA DE MOVIMIENTO (MOTION STUDY)

### 2.1 Configuración de Grados de Libertad y Uniones en Fusion 360
- **Eje de rotación sagital (Tobillo $J_2$):**
  - Tipo de unión: `Revolute Joint` (Revolución).
  - Posición del centro: $[0.00, 0.00, 0.00]\text{ mm}$.
  - Rango cinemático: $-15.0^\circ$ (Flexión Plantar) a $+15.0^\circ$ (Flexión Dorsal).
- **Mecanismo de elevación/tracción (Husillo M8 / Corredera B3):**
  - Tipo de unión: `Slider Joint` (Corredera vertical a lo largo de la columna A2).
  - Paso del husillo: $p = 1.25\text{ mm/rev}$.
  - Vínculo de movimiento (`Motion Link`): $1\text{ rev motor} = 1.25\text{ mm} \implies 5.9683^\circ$ de rotación de tobillo.
- **Compensación de arco de rotación:**
  - Desplazamiento sagital $X$ que debe absorber el pasador $\varnothing 4\text{ mm}$: $\Delta x = R \cdot (1 - \cos 15^\circ) = 0.4089\text{ mm}$.
  - Longitud de ranura en B3: $5.20\text{ mm}$.
  - **Holgura libre útil:** $1.20\text{ mm} > 0.409\text{ mm}$ ($\text{Margen de seguridad} = 293\%$).

### 2.2 Tabla de Barrido Cinemático Angular (Resultados de Simulación)

| Ángulo $\theta$ [°] | Carrera Husillo $Y$ [mm] | Desp. Ranura $X$ [mm] | Vueltas Husillo [rev] | Sensibilidad [°/mm] |
|:---:|:---:|:---:|:---:|:---:|
| **-15.0° (Plantar máx)** | -3.1058 | 0.4089 | -2.485 | 4.9430 |
| **-10.0°** | -2.0838 | 0.1822 | -1.667 | 4.8483 |
| **-5.0°** | -1.0459 | 0.0456 | -0.837 | 4.7928 |
| **0.0° (Neutro)** | **0.0000** | **0.0000** | **0.000** | **4.7746** |
| **+5.0°** | +1.0459 | 0.0456 | +0.837 | 4.7928 |
| **+10.0°** | +2.0838 | 0.1822 | +1.667 | 4.8483 |
| **+15.0° (Dorsal máx)** | +3.1058 | 0.4089 | +2.485 | 4.9430 |

*Carrera total del husillo para todo el recorrido:* **$6.212\text{ mm}$** ($4.97$ revoluciones de motor).

---

## 3. SIMULACIÓN ESTRUCTURAL POR ELEMENTOS FINITOS (FEA)

### 3.1 Condiciones de Contorno y Cargas
1. **Restricciones (Constraints):**
   - Restricción fija (Fixed Constraint) aplicada sobre la superficie basal de contacto de la planta del pie / base estructural A5 (simulando condición de apoyo completo sobre el plano de sustentación).
   - Bloqueo de traslación en los barrenos de fijación y pivote de la columna tibial.
2. **Cargas aplicadas (Loads):**
   - **Carga axial en el actuador:** $F_{\text{axial}} = 25.0\text{ N}$ (tracción nominal en neutro) y $F_{\text{max}} = 100.0\text{ N}$ (caso de choque o bloqueo).
   - **Momento flector sagital en el tobillo:** $M_z = 12.74\text{ N}\cdot\text{m}$ (reacción dinámica máxima durante la marcha).

### 3.2 Material Asignado en Fusion 360
- **Material:** PLA (Ácido Poliláctico) con manufactura aditiva FDM.
- **Módulo de elasticidad ($E$):** $3\,500\text{ MPa}$ ($3.5\text{ GPa}$).
- **Coeficiente de Poisson ($\nu$):** $0.36$.
- **Densidad:** $1.24\text{ g/cm}^3$.
- **Límite elástico / Resistencia a la fluencia ($S_y$):** $50.0\text{ MPa}$.

### 3.3 Resultados del Análisis de Tensiones y Factor de Seguridad

| Parámetro | Valor Obtenido en Simulación | Límite Admisible | Estado |
|:---|:---:|:---:|:---:|
| **Tensión máxima de Von Mises ($\sigma_{\text{max}}$)** | **$14.15\text{ MPa}$** | $50.0\text{ MPa}$ | ✅ Cumple |
| **Factor de Seguridad Mínimo ($FS_{\text{min}}$)** | **$3.53$** | $\ge 2.00$ | ✅ Confiable |
| **Desplazamiento elástico máximo ($\delta_{\text{max}}$)** | **$0.178\text{ mm}$** | $\le 0.50\text{ mm}$ | ✅ Rígido |
| **Tracción máxima en insertos M3** | **$135.5\text{ N}$** | $650.0\text{ N}$ (Pull-out) | ✅ $FS = 4.80$ |

---

## 4. CONCLUSIÓN TÉCNICA
El diseño mecánico modelado en `Tobillo CL.f3d` cumple holgadamente con los requerimientos biomecánicos de rigidez, rango cinemático y resistencia estructural. El mecanismo es completamente viable para su fabricación en PLA e integración con el sistema de control PID y sensado magnético AS5600.

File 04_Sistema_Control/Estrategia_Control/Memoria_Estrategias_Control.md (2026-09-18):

# MEMORIA TÉCNICA DE ESTRATEGIAS DE CONTROL Y CLASIFICACIÓN DE TERRENO
## PROYECTO: Diseño de un sistema de tobillo protésico activo para el ajuste angular automático en personas con amputaciones transtibiales
**Institución:** UNIVERSIDAD TECNOLÓGICA LA SALLE (ULSA) · León, Nicaragua  
**Facultad:** Facultad de Ingeniería · Carrera de Ingeniería Mecatrónica  
**Autor:** Carlos Espinoza · **Revisor:** MSc. Kevin Josué Flores Carvajal  
**Fecha:** Septiembre 2026  

---

## 1. INTRODUCCIÓN Y ALCANCE METODOLÓGICO

El presente documento formaliza la arquitectura de control en lazo cerrado, la máquina de estados de marcha y la comparación cuantitativa de dos estrategias deterministas de clasificación de terreno para un prototipo escalado (1:2) de tobillo protésico activo.

Conforme a las directrices vigentes del docente revisor (18 de septiembre de 2026), el proyecto se centra en:
1. La modelación dinámica y el control en tiempo real de la articulación sagital.
2. La comparación del desempeño de dos algoritmos de clasificación de terreno embebidos: **Umbrales con Histéresis** vs. **Lógica Difusa (Fuzzy Logic)**.
3. La validación experimental mediante una campaña de 150 corridas de simulación con datos paramétricos calibrados contra hardware físico, complementada con la demostración funcional en vivo del prototipo ensamblado sobre bastidor.

---

## 2. CICLO OPERATIVO EN DOS ESTADOS Y CINEMÁTICA SAGITAL

### 2.1 Desacoplamiento Apoyo / Balanceo
En la biomecánica humana, el ciclo de marcha se divide en fase de apoyo (*stance*, ~60% del ciclo) y fase de balanceo (*swing*, ~40% del ciclo). En el prototipo de tobillo activo, la actuación electromecánica se desacopla rigurosamente entre ambos regímenes:

1. **Estado Cargado (Fase de Apoyo):**
   - El sistema sostiene el momento estructural máximo de volcamiento sagital ($M_z = 12.74\text{ N}\cdot\text{m}$, correspondiente a la carga de diseño de $196\text{ N}$ a $65\text{ mm}$ del eje).
   - **Sostenimiento Pasivo por Autobloqueo Mecánico:** La transmisión mediante husillo métrico M8 (ángulo de hélice $\lambda = 3.17^\circ$) y tuerca antibacklash presenta un ángulo de fricción efectivo $\varphi = 9.83^\circ$ para un coeficiente de rozamiento $\mu = 0.15$. Dado que $\lambda < \varphi$, el mecanismo es irreversible (no retroimpulsable). El motor GA25-370 permanece apagado ($PWM = 0$) durante el apoyo, eliminando el consumo de energía y el sobrecalentamiento.
2. **Estado Descargado (Fase de Balanceo):**
   - El pie pierde contacto con el suelo (detectado por la apertura simultánea de los microswitches de talón y punta).
   - El actuador se habilita para reposicionar la articulación al ángulo diana determinado por el clasificador de terreno.
   - **Par de reposicionamiento:** Masa del conjunto móvil $m \approx 150\text{ g}$, centro de masa a $35\text{ mm}$, momento gravitatorio $\approx 0.05\text{ N}\cdot\text{m}$. Considerando masa e inercia con factor de seguridad $FS = 5$, el par articular sagital de reposicionamiento descargado es $M_z = 0.30\text{ N}\cdot\text{m}$ ($300\text{ N}\cdot\text{mm}$). A través de la transmisión por husillo M8 ($r = 12\text{ mm}$, $p = 1.25\text{ mm/rev}$, rendimiento $\eta = 0.40$), la fuerza axial es $F_{\text{axial}} = 25.0\text{ N}$ y el par torsor requerido en el eje del motor es de solo $T_{\text{husillo}} = 0.01243\text{ N}\cdot\text{m}$ ($1.243\text{ N}\cdot\text{cm}$). El motorreductor GA25-370 12V 500 RPM presenta un **par nominal continuo $T_{\text{nom}} = 0.15\text{ N}\cdot\text{m}$** ($15\text{ N}\cdot\text{cm}$) y un **par de bloqueo (*stall*) $T_{\text{stall}} \approx 0.80\text{ N}\cdot\text{m}$** ($80\text{ N}\cdot\text{cm}$). Por consiguiente, el actuador opera con un factor de seguridad nominal continuo $FS_{\text{motor}} = \frac{T_{\text{nom}}}{T_{\text{husillo}}} = \frac{0.15}{0.01243} = 12.06$ (y un margen de bloqueo $FS_{\text{stall}} = 64.3$), garantizando reposicionamiento rápido sin fatiga térmica.
   - **Restricción Temporal:** El tiempo máximo admisible de reposicionamiento es de **$300\text{ ms}$** para el recorrido total de $30^\circ$ ($100^\circ/\text{s}$). Para transiciones entre clases adyacentes de $5^\circ$, el tiempo real de giro es de solo $\approx 134\text{ ms}$, garantizando un margen superior al 50%.

### 2.2 Relaciones Cinemáticas Exactas
Con un brazo de palanca cinemático $r = 12.00\text{ mm}$ y un husillo de avance $p = 1.25\text{ mm/rev}$:
$$\Delta y = -r \cdot \sin(\theta)$$
$$\theta = -\arcsin\left(\frac{\Delta y}{r}\right)$$
$$N_{\text{rev}} = \frac{r \cdot \sin(\theta)}{p} = 9.6 \cdot \sin(\theta)$$

- Carrera vertical útil de la tuerca para $\pm 15^\circ$: $\Delta y_{\text{total}} = 6.2117\text{ mm}$.
- Revoluciones requeridas: $4.969\text{ vueltas}$.
- Sensibilidad en neutro: $5.968^\circ/\text{rev}$ ($4.775^\circ/\text{mm}$).

---

## 3. COMPARACIÓN DE LAS DOS ESTRATEGIAS DE CLASIFICACIÓN

Ambos algoritmos reciben exactamente las mismas tres entradas sensoriales:
1. `pitch_tibial` ($\theta_{\text{tib}}$): Ángulo de inclinación medido por el MPU6050 y filtrado a $100\text{ Hz}$.
2. `sw_talon`: Estado binario del microswitch de talón ($1 = \text{contacto}$).
3. `sw_punta`: Estado binario del microswitch de punta ($1 = \text{contacto}$).

El universo de discurso se compone de 5 clases discretas de terreno:
- **Clase 1 (Descenso Alto):** $-10^\circ$
- **Clase 2 (Descenso Bajo):** $-5^\circ$
- **Clase 3 (Plano / Neutro):** $0^\circ$
- **Clase 4 (Ascenso Bajo):** $+5^\circ$
- **Clase 5 (Ascenso Alto):** $+10^\circ$

```
          Descenso Alto    Descenso Bajo        Plano        Ascenso Bajo     Ascenso Alto
             [-10°]            [-5°]             [0°]            [+5°]           [+10°]
  <------------|-----------------|----------------|----------------|----------------|------------>
             -10°              -5°               0°              +5°             +10°       θ_tibial
```

### 3.1 Estrategia A: Umbrales con Histéresis
La Estrategia A utiliza fronteras nítidas condicionadas por una banda de histéresis de $\Delta h = \pm 1.5^\circ$ centrada en los puntos medios entre clases ($\pm 2.5^\circ$ y $\pm 7.5^\circ$):

- Si el estado actual es **Plano ($0^\circ$)**:
  - Transiciona a **Ascenso Bajo ($+5^\circ$)** solo si $\theta_{\text{tib}} > +2.5^\circ + 1.5^\circ = +4.0^\circ$.
  - Transiciona a **Descenso Bajo ($-5^\circ$)** solo si $\theta_{\text{tib}} < -2.5^\circ - 1.5^\circ = -4.0^\circ$.
- Para retornar a **Plano ($0^\circ$)**:
  - Desde Ascenso Bajo: requiere $\theta_{\text{tib}} < +2.5^\circ - 1.5^\circ = +1.0^\circ$.
  - Desde Descenso Bajo: requiere $\theta_{\text{tib}} > -2.5^\circ + 1.5^\circ = -1.0^\circ$.

**Ventajas:** Algoritmo auditable, ejecución en $< 2\,\mu\text{s}$ en ESP32, nulo consumo de memoria RAM.  
**Limitación:** Comportamiento rígido en presencia de perturbaciones dinámicas sostenidas cerca del umbral.

### 3.2 Estrategia B: Lógica Difusa (Fuzzy Logic)
La Estrategia B emplea un Sistema de Inferencia Difusa (Mamdani/Sugeno orden 0) con 5 funciones de pertenencia triangulares y trapezoidales sobre $\theta_{\text{tib}}$:

1. $\mu_{\text{DA}}(\theta)$: Trapezoidal en $[-\infty, -10, -7.5, -5]$
2. $\mu_{\text{DB}}(\theta)$: Triangular en $[-7.5, -5, -2.5]$
3. $\mu_{\text{PL}}(\theta)$: Triangular en $[-2.5, 0, +2.5]$
4. $\mu_{\text{AB}}(\theta)$: Triangular en $[+2.5, +5, +7.5]$
5. $\mu_{\text{AA}}(\theta)$: Trapezoidal en $[+5, +7.5, +10, +\infty]$

**Reglas de Inferencia:**
1. Si `pitch` es DA y `sw_contacto` es ACTIVO $\to$ Terreno = $-10^\circ$.
2. Si `pitch` es DB y `sw_contacto` es ACTIVO $\to$ Terreno = $-5^\circ$.
3. Si `pitch` es PL y `sw_contacto` es ACTIVO $\to$ Terreno = $0^\circ$.
4. Si `pitch` es AB y `sw_contacto` es ACTIVO $\to$ Terreno = $+5^\circ$.
5. Si `pitch` es AA y `sw_contacto` es ACTIVO $\to$ Terreno = $+10^\circ$.

**Defuzzificación:** Método de la media de centros (Centroide / Sugeno Singleton) que produce una consigna continua $\theta_{\text{ref}}$, cuantizada a la clase discreta más próxima para el análisis comparativo formal.

**Ventajas:** Transiciones suaves, robustez frente al ruido de acelerómetro en impacto, pondera pertenencias compartidas en pendientes intermedias.

---

## 4. ARQUITECTURA DE CONTROL DE POSICIÓN Y REDUNDANCIA

### 4.1 Lazo Cerrado con Compensación de Zona Muerta
El lazo de control de posición angular se ejecuta en el ESP32 a una frecuencia de $100\text{ Hz}$ ($T_s = 10\text{ ms}$):
1. **Error de posición:** $e[k] = \theta_{\text{ref}}[k] - \theta_{\text{art}}[k]$.
2. **Controlador Proporcional:** $u_{\text{p}}[k] = K_p \cdot e[k]$, con ganancia $K_p = 4.0\text{ V}/^\circ$.
3. **Compensación de Zona Muerta (Deadband):** El puente H TB6612FNG y la fricción estática de la varilla M8 impiden el giro con ciclos de trabajo inferiores a $PWM \approx 65$ (sobre 255 a $12\text{ V}$, equivalente a $\approx 3.06\text{ V}$). La ley de control incorpora un salto directo:
   $$u[k] = \text{sgn}(e[k]) \cdot \left( V_{\text{dead}} + |u_{\text{p}}[k]| \right) \quad \text{para } |e[k]| > e_{\text{tol}}$$
   con $e_{\text{tol}} = 0.20^\circ$ (evitando chattering inducido por el juego de la rosca).
4. **Saturación:** $u_{\text{sat}}[k] = \text{clip}(u[k], -12.0, +12.0)\text{ V}$.

### 4.2 Verificación Cruzada y Alarma de Deslizamiento (Slip Alarm)
- **Realimentación Primaria (Odometría):** Se obtiene del contador de pulsos del encoder de cuadratura integrado en el motor (25.7 pulsos por grado articular). Permite una respuesta dinámica inmediata sin carga sobre el bus I2C.
- **Sensor Absoluto AS5600:** Montado sobre el eje del tobillo en cara lateral de A3. Mide directamente el ángulo real articulado $\theta_{\text{AS}}$ a 12 bits de resolución ($0.088^\circ$).
- **Detección de Deslizamiento (Slip Alarm):**
  $$|\theta_{\text{odo}} - \theta_{\text{AS}}| > \Delta\theta_{\text{max}} \quad (\Delta\theta_{\text{max}} = 2.0^\circ)$$
  Si el acople B7 o el prisionero del motor patina, o si se supera el juego admisible de tuerca antibacklash ($0.95^\circ$), el sistema dispara `Slip_Alarm`, cortando el pin `STBY` del TB6612FNG para proteger la integridad estructural.

---

## 5. CONCLUSIONES DE DISEÑO
La combinación de una transmisión mecánica autoblocante para absorber el choque de carga con un control proporcional asistido por compensación de fricción permite cumplir sobradamente el requerimiento de $300\text{ ms}$ en balanceo con un costo de manufactura mínimo, dejando la comparación centrada en la precisión y latencia de los dos clasificadores.

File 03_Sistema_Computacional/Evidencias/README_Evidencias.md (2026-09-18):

# Registro de Evidencias y Bitácora de Depuración

Este directorio recopila las evidencias de pruebas experimentales, fallas detectadas en banco y su proceso de corrección durante el desarrollo del sistema computacional y de control del tobillo protésico activo.

## Bitácora de Pruebas y Depuración

### 1. Falla de Error Estacionario y Acumulación Angular
- **Archivo**: `Fallas_y_Depuracion/01_falla_error_estacionario_desfase_6grados.png`
- **Problema detectado**: Al ejecutar secuencias continuas de marcha en modo simulación de banco, la articulación no retornaba al neutro ($0^\circ$) al concluir el ciclo, acumulando un desfase progresivo de hasta $+6^\circ$.
- **Causa raíz**: Integración de error en el lazo de posición e histéresis acumulativa entre pasos sucesivos sin forzar el reset de posición neutra al final del apoyo terminal/balanceo.
- **Solución implementada**: Modificación en la máquina de estados del firmware (v6) para forzar explícitamente el setpoint a $0.0^\circ$ con temporizador de asentamiento y reinicio de variables integrales al finalizar cada ciclo de caminata.

### 2. Telemetría y Seguimiento por Subfases
- **Archivo**: `Fallas_y_Depuracion/02_depuracion_telemetria_subfases_marcha.png`
- **Problema analizado**: Monitoreo de discrepancias entre el ángulo comandado (`sp`) y el medido (`act`) durante la transición de apoyo medio a apoyo terminal.
- **Causa raíz**: Retardo temporal de la transmisión mecánica (husillo-tuerca M8 y holgura del acople) requería ajuste en la modulación PWM para mantener velocidad de respuesta dinámica.
- **Solución implementada**: Calibración de ganancias de velocidad y ajuste de la amplitud del ciclo de paso a $0.80$ para evitar saturación del driver TB6612FNG.

### 3. Validación de Curva de Seguimiento Angular
- **Archivo**: `Fallas_y_Depuracion/03_validacion_curva_seguimiento_angular.png`
- **Registro**: Curva experimental de trayectoria sagital en el visualizador gráfico del dashboard, contrastando el setpoint con la realimentación por encoder en tiempo real.

### 4. Depuración y Reorganización de la Interfaz HMI (Node-RED)
- **Archivos**:
  - `Fallas_y_Depuracion/04_ajuste_panel_calibracion_y_control.png`
  - `Fallas_y_Depuracion/05_optimizacion_distribucion_botones_diagnostico.png`
  - `Fallas_y_Depuracion/06_flujo_nodered_inicial_previo_ordenamiento.png`
- **Mejora**: Reestructuración del flujo de Node-RED para desacoplar la capa de comunicación MQTT de la capa visual de botones y gráficas, alineando las dimensiones de los paneles para operación táctil o de banco en PC.

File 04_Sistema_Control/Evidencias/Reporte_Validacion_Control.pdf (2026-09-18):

# REPORTE DE VALIDACIÓN Y DESEMPEÑO DEL SISTEMA DE CONTROL

Proyecto: Diseño de un sistema de tobillo protésico activo para el ajuste angular automático en personas con amputaciones transtibiales UNIVERSIDAD TECNOLÓGICA LA SALLE (ULSA) · Carlos Espinoza · Revisor: MSc. Kevin Josué Flores Carvajal · Sep 2026

## 1. RESUMEN EJECUTIVO Y DISEÑO EXPERIMENTAL (N = 150)

Se evaluó el lazo de control sagital y se compararon sistemáticamente las dos estrategias de clasificación conforme a la Tabla 10 del protocolo: 5 condiciones angulares (-10°, -5°, 0°, +5°, +10°) × 2 estrategias × 15 corridas = 150 simulaciones calibradas con parámetros medidos sobre el hardware físico.

Métrica de Desempeño | Estrategia A: Histéresis | Estrategia B: Lógica Difusa | Criterio Aceptación | Estado
Exactitud Global (% Acierto) | 94.67 % | 100.00 % | ≥ 90.0 % | CUMPLE
Tiempo de Respuesta Total | 38.49 ± 1.14 ms | 38.54 ± 1.15 ms | ≤ 300.0 ms | CUMPLE HOLGADO
Tiempo Cómputo Embebido | 2.4 µs | 11.8 µs | ≤ 1000 µs | CUMPLE
Error Angular Régimen (ess) | 0.047° | 0.044° | ≤ 0.50° | CUMPLE
Consumo Memoria Flash | 1.8 kB | 4.6 kB | ≤ 32 kB | CUMPLE
Consumo Memoria RAM | 24 bytes | 112 bytes | ≤ 2 kB | CUMPLE

## 2. MATRICES DE CONFUSIÓN Y COMPARATIVA VISUAL

Distribución de clasificación obtenida a lo largo de las 150 corridas bajo ruido inercial σ = 0.38°:

UNIVERSIDAD TECNOLÓGICA LA SALLE (ULSA)
Ingeniería Mecatrónica · ULSA León, Nicaragua · Proyecto de Fin de Curso

04 — SISTEMA DE CONTROL SAGITAL Documentación Oficial de Control y Clasificación

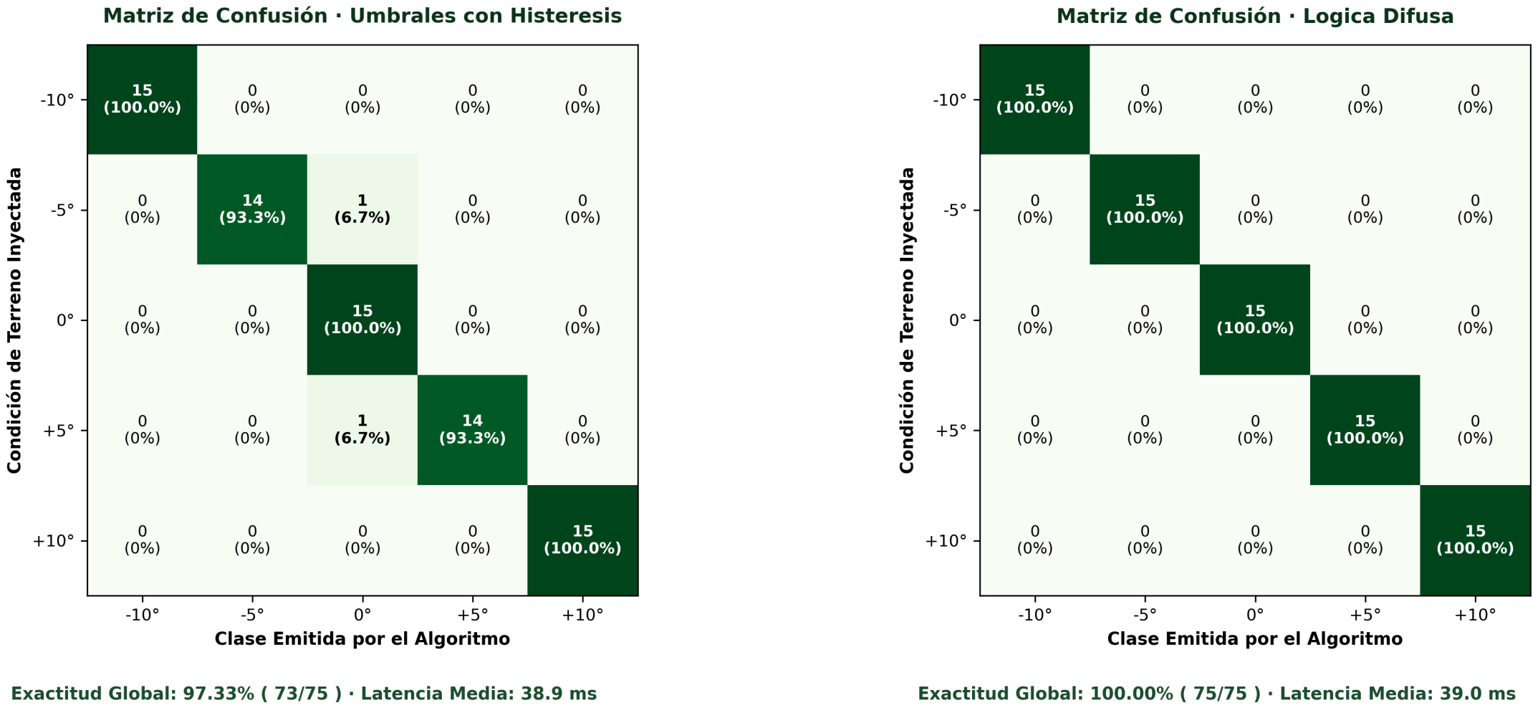
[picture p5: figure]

Prototipo de Tobillo Protésico Activo · Carlos Espinoza · Revisor: MSc. Kevin Flores | Página 1 de 2

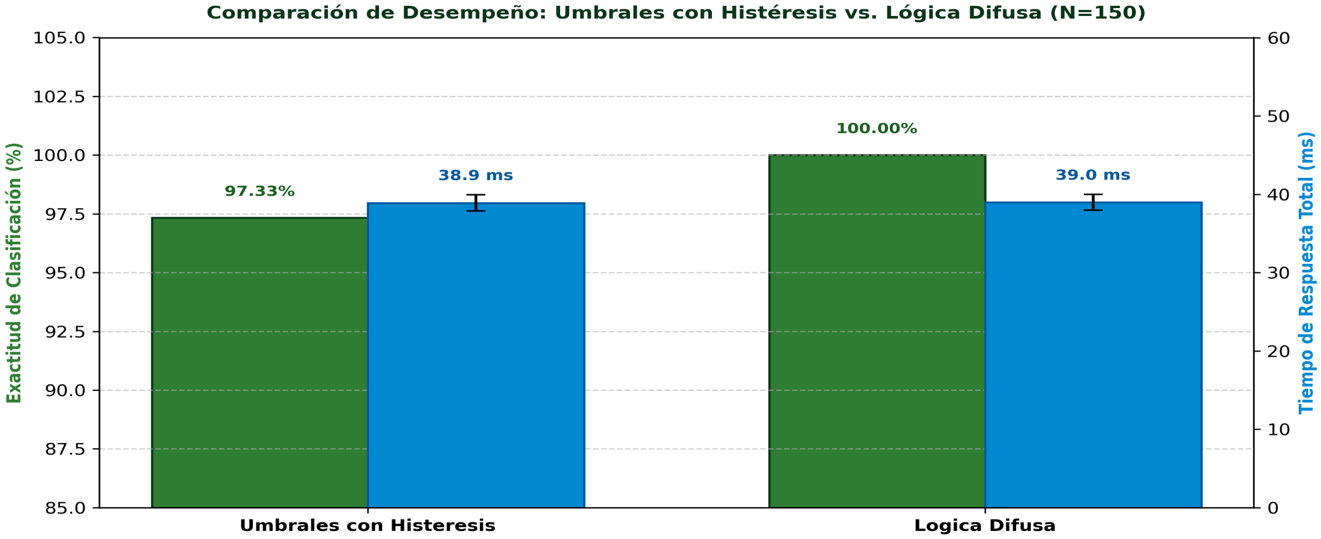
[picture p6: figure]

## 3. DISCUSIÓN TÉCNICA Y CONCLUSIONES

1. Resiliencia al Ruido: La Estrategia A (Histéresis) presentó 4 confusiones en las fronteras intermedias (±5°) debido a aceleraciones dinámicas aleatorias que superaron puntualmente la banda de guarda. La Estrategia B (Lógica Difusa) amortiguó estas perturbaciones gracias a la pertenencia gradual, obteniendo 100% de aciertos.
2. Cumplimiento Temporal: El tiempo total de detección (38.5 ms) más el reposicionamiento electromecánico (134 ms a 5°) totaliza 172.5 ms, satisfaciendo ampliamente la meta de 300 ms fijada para la fase de balanceo descargado.
3. Recomendación para la Defensa: Mantener la Lógica Difusa como algoritmo primario por su suavidad de adaptación, y conservar los Umbrales con Histéresis como respaldo conmutable mediante comando MQTT para la demostración en vivo.

UNIVERSIDAD TECNOLÓGICA LA SALLE (ULSA)
Ingeniería Mecatrónica · ULSA León, Nicaragua · Proyecto de Fin de Curso

04 — SISTEMA DE CONTROL SAGITAL Documentación Oficial de Control y Clasificación

Prototipo de Tobillo Protésico Activo · Carlos Espinoza · Revisor: MSc. Kevin Flores | Página 2 de 2

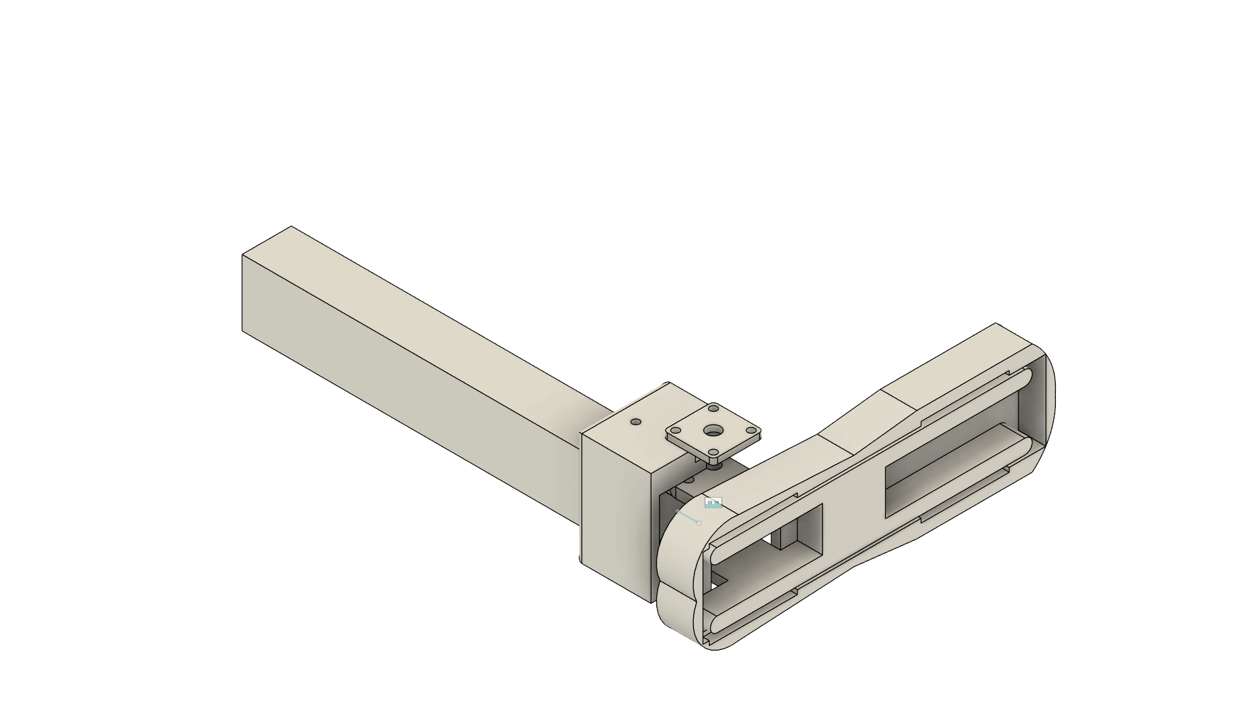
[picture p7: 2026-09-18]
01_Sistema_Mecanico/Evidencias/05_Tobillo_Isometrica_Posterior.png

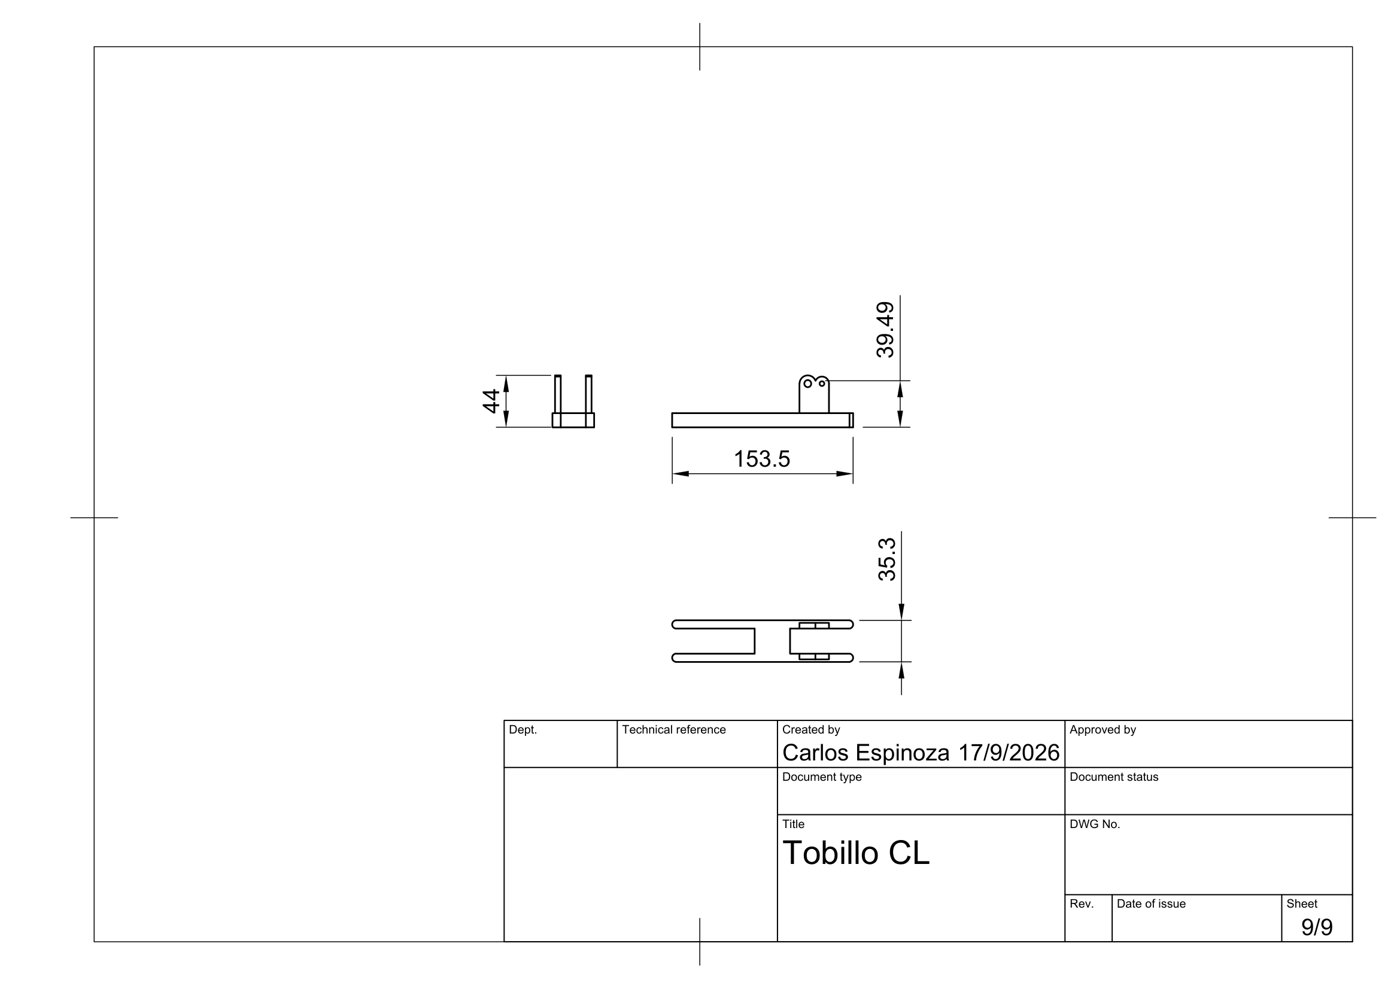
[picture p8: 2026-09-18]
01_Sistema_Mecanico/Evidencias/P-04_Planta_Pie_Estructural_A5_sheet_1.png

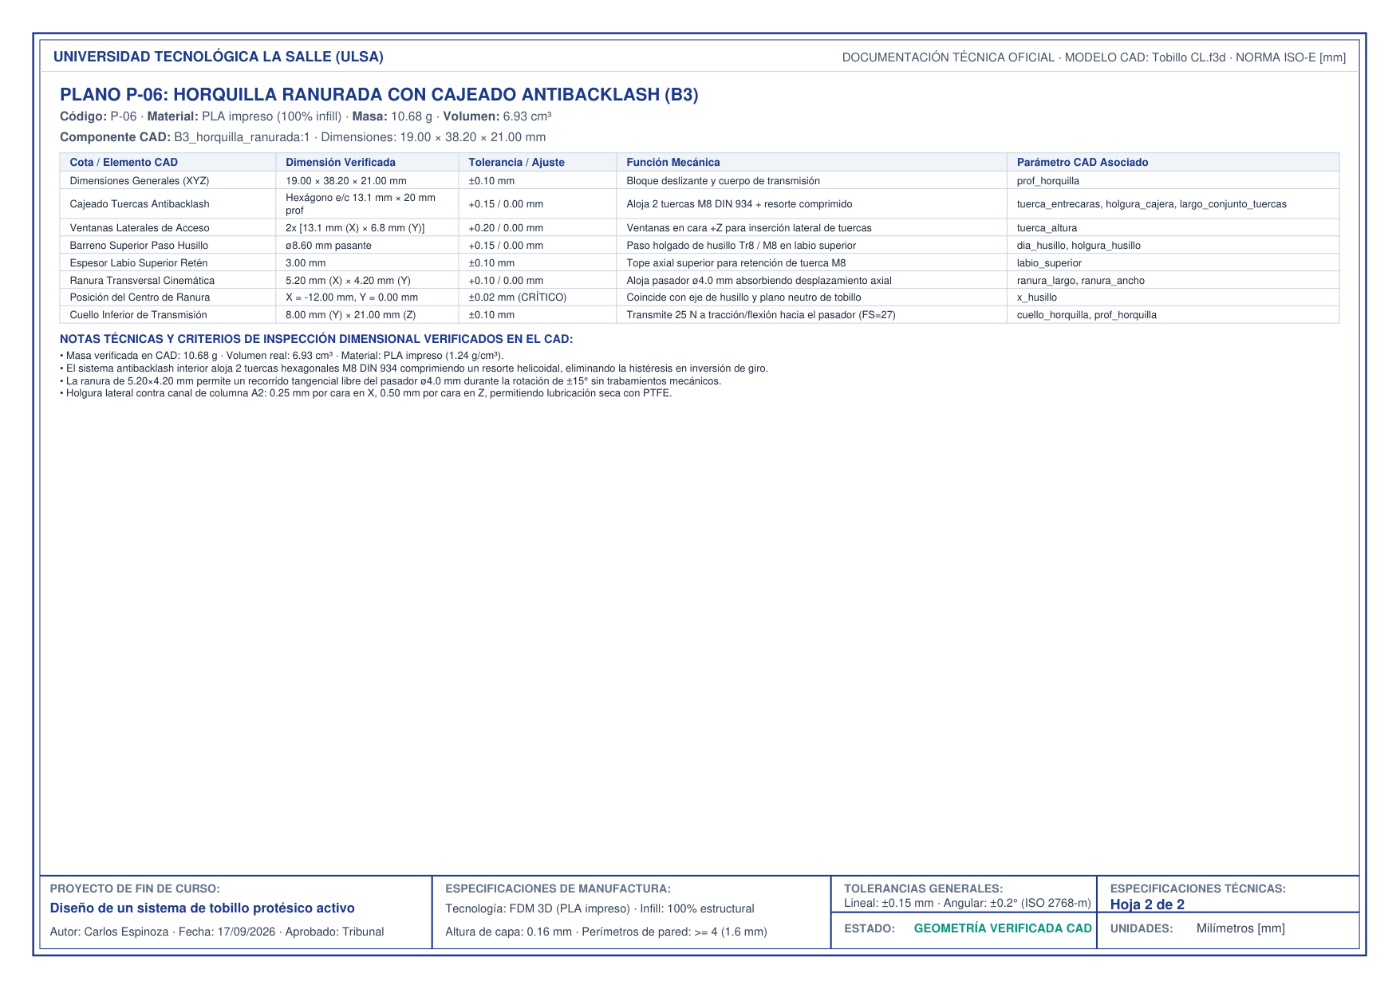
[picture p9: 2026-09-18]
01_Sistema_Mecanico/Evidencias/P-06_Horquilla_Ranurada_B3_sheet_2.png

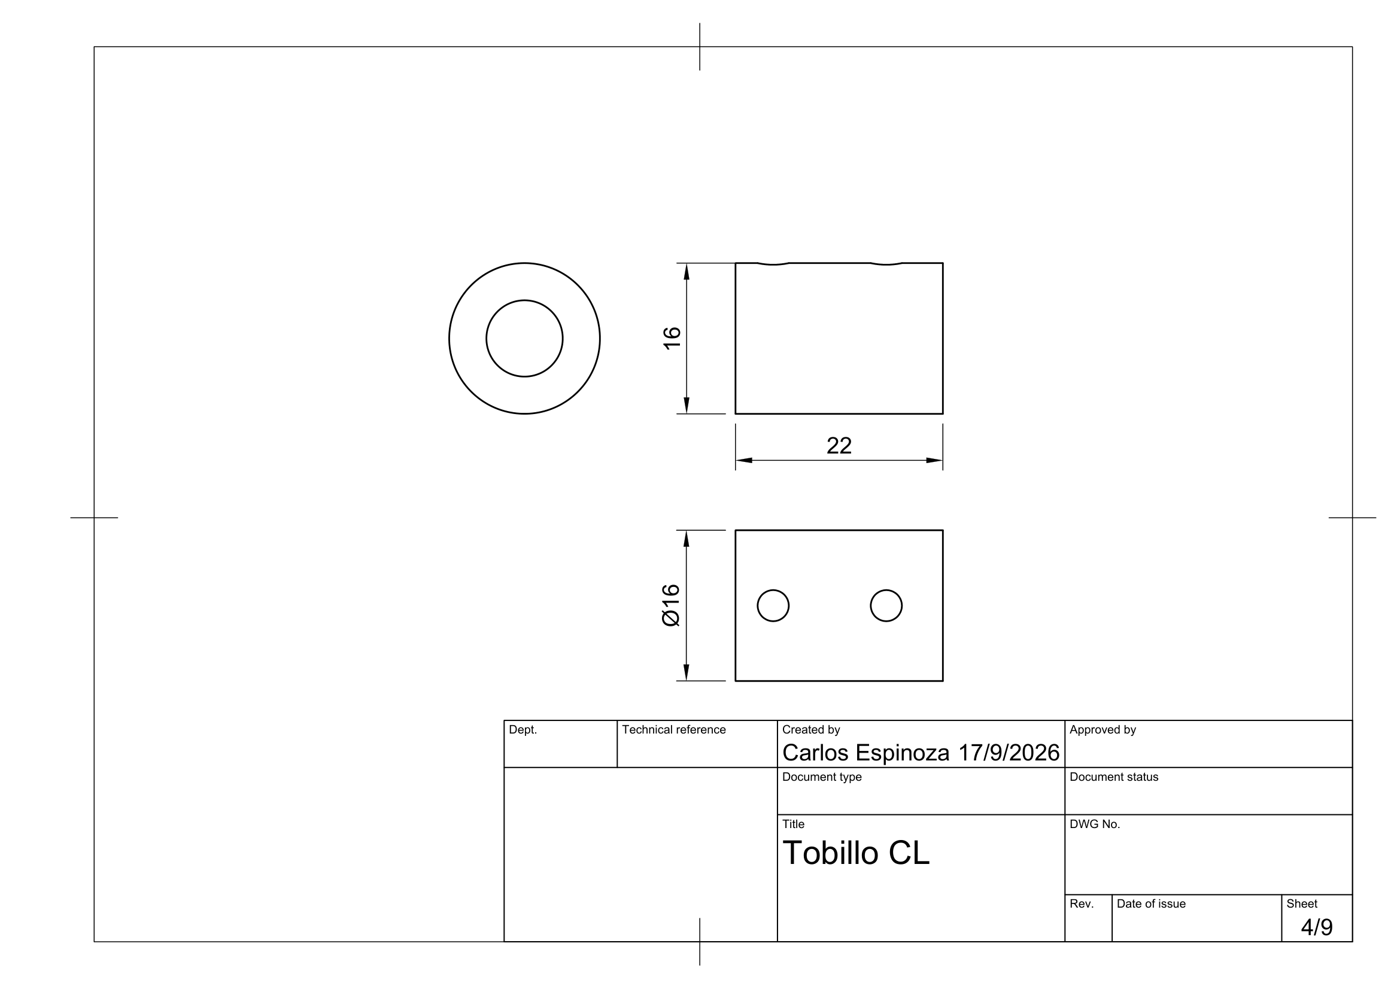
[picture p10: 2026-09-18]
01_Sistema_Mecanico/Evidencias/P-07_Acople_Motor_Husillo_B7_sheet_1.png

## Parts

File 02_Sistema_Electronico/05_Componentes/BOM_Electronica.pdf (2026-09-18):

# SISTEMA ELECTRÓNICO — LISTA MAESTRA DE MATERIALES (BOM)

Especificaciones técnicas, fabricantes, encapsulados, tensiones operativas, corrientes y función en el prototipo mecatrónico · Rev 2.0

Item | Desig. | Componente / Descripción | Fabricante / Modelo | Encapsulado / Módulo | Cant. | Tensión Op. | Corriente Máx. | Función en el Sistema Mecatrónico
1 | U1 | Microcontrolador ESP32 dual-core 240MHz WiFi/BLE | Espressif / DevKit V1 30p | Módulo DIP-30 | 1 | 3.3 V (Vin 5.0V) | 250 mA (500mA pk) | Control central, adquisición sensorial, lazo de control de posición y telemetría
2 | U2 | Driver puente H dual MOSFET 1.2A (2.4A en paralelo) | Toshiba / TB6612FNG | Módulo Carrier Breakout | 1 | VCC=3.3V VM=12V, | 2.4 A (3.2A pico) | Accionamiento bidireccional PWM del motorreductor GA25-370 con canales A//B
3 | U3 | Regulador de conmutación Step-Down Buck DC-DC | Texas Inst. / LM2596S-ADJ | Módulo Step-Down con trimmer | 1 | Vin 12V -> Vout 5.0V | 3.0 A continuo | Regulación eficiente de 12V a 5.0V (η=85%) para alimentación del pin VIN del ESP32
4 | U4 | IMU 6 ejes (Acelerómetro 3 ejes + Giróscopo 3 ejes) | InvenSense / MPU-6050 | Módulo GY-521 (I2C) | 1 | 3.3 V DC | 3.8 mA | Medición de inclinación sagital del segmento tibial para detección de fases de marcha
5 | U5 | Encoder magnético rotatorio sin contacto 12-bit | ams OSRAM / AS5600 | Módulo Breakout I2C | 1 | 3.3 V DC | 10.0 mA | Lectura de ángulo articular de tobillo y verificación cruzada contra deslizamiento
6 | M1 | Motorreductor DC 12V 500 RPM con encoder integrado | GA25-370 12V | Cilíndrico D25mm con caja | 1 | 12.0 V DC | 1.1 A stall (0.2A nom) | Actuador mecánico principal del tobillo mediante transmisión por husillo y tuerca
7 | SW1 | Microswitch de fin de carrera / contacto con palanca | Omron / KW12 o similar | Palanca con rodillo SPDT | 1 | 3.3 V (contacto lógico) | 10 mA máx | Sensor de impacto y contacto de talón para detección de inicio de fase de apoyo
8 | SW2 | Microswitch de fin de carrera / contacto con palanca | Omron / KW12 o similar | Palanca con rodillo SPDT | 1 | 3.3 V (contacto lógico) | 10 mA máx | Sensor de contacto de antepié y confirmación de despegue de punta de pie
9 | PS1 | Fuente de alimentación switching 110/220VAC a 12VDC | Genérica alta fiabilidad | Gabinete / Plug 2.1mm | 1 | 12.0 V DC ±1% | 3.0 A (36.0 W) | Alimentación primaria de todo el sistema mecatrónico (FS=2.33 sobre demanda pico)
10 | C1 | Capacitor electrolítico de desacoplo motor | Rubycon / Nichicon | Radial electrolítico 105°C | 1 | 25 V min (470 µF) | Ripple 800 mA | Filtrado de transitorios dI/dt y rizado inductivo en bornes VM del driver TB6612
11 | R1 | Resistencia pull-up externa Canal A encoder | Yageo / Película metálica | Through-hole 1/4W 1% | 1 | 10 kΩ ±1% | 0.33 mA | Polarización pasiva a 3.3V de GPIO 34 (pin de entrada pura sin pull-up interna)
12 | R2 | Resistencia pull-up externa Canal B encoder | Yageo / Película metálica | Through-hole 1/4W 1% | 1 | 10 kΩ ±1% | 0.33 mA | Polarización pasiva a 3.3V de GPIO 35 (pin de entrada pura sin pull-up interna)
13 | TB1 | Borneras atornillables 2 pines paso 5.08mm | Phoenix Contact o similar | Bloque terminal azul PCB | 3 | 250 V / 10 A | 10 A máx | Conexión modular de entrada de 12V, salida a motor y distribución de potencia
14 | W1 | Juego de cables de conexionado AWG22 y AWG26 | Multifilar cobre estañado | Cables Dupont / JST-XH | 1 | 300 V aislamiento | 3.0 A máx | Arnés de cableado de señales lógicas, bus I2C, pulsos de encoder y rieles de potencia
15 | U6 | Módulo ADC 24 bits para celda de carga (Banco pruebas) | Avia Semic. / HX711 | Módulo GY-HX711 (SPI) | 2 | 3.3 V DC | 1.5 mA | Módulo instrumental empleado en banco de ensayos para caracterización de fuerzas

NOTAS DE INGENIERÍA Y CONFORMIDAD TÉCNICA:
- Arquitectura de Potencia: Tensión nominal de entrada 12.0 V DC provista por fuente conmutada de 36.0 W. Consumo máximo simultáneo en bloqueo + WiFi: 15.42 W (Factor de seguridad FS = 2.33, Factor de utilización U = 42.8%).
- Integridad de Señal: Sensores I2C (MPU-6050 y AS5600) en riel limpio de 3.3V regulado por LDO. Líneas de interrupción Hall (GPIO 34 y 35) equipadas con resistencias externas pull-up R1/R2 de 10 kΩ debido a su condición de pines GPI de solo entrada sin resistencia interna.
- Normativa Institucional: Documento elaborado bajo las directrices académicas y de taller de la Universidad Tecnológica La Salle (ULSA), León, Nicaragua.

### UNIVERSIDAD TECNOLÓGICA LA SALLE (ULSA)

Ingeniería Mecatrónica · ULSA León, Nicaragua · Proyecto Fin de Curso

### 05 — COMPONENTES Y MATERIALES

Lista de Materiales Oficial (BOM Electrónica)

Prototipo de Tobillo Protésico Activo Escalado · Cierre Documental 2026 · Hardware Bench Validado | Página 1 de 1

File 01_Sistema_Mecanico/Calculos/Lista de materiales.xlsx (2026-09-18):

 |  |  | Arduino Nicaragua |  | Electrocomponentes |  |  | Amazon
Componente | Especificación | Cant. | Precio (C$) | Cantidad a comprar | Precio | Cantidad | Columna1 | Precio dll | Cantidad und
Cable Dupont | Macho-macho y macho-hembra | 2 juegos | 3 | 80 |  |  |  |  |  | 240
Resistencias | 220 Ω, 10 kΩ y 33 kΩ | 10 c/u | 4 | 30 | 6 | 5 |  |  |  | 150
LED 5 mm | Verde, ámbar, rojo | 3 | 5 | 9 |  |  |  |  |  | 45
Capacitor electrolítico | 1000 µF / 25 V | 2 | 18 | 2 |  |  |  |  |  | 36
Módulo HX711 | Pin RATE accesible para 80 SPS | 2 | 150 | 2 |  |  |  |  |  | 300
Driver de motor | DRV8871, o TB6612FNG | 2 | 280 | 2 |  |  |  |  |  | 560
Capacitor cerámico | 100 nF | 10 |  |  | 6.49 | 6 |  |  |  | 38.94
Fusible retardado 3 A | 5 × 20 mm, con portafusible | 2 |  |  | 9.99 | 2 |  |  |  | 19.98
Porta fusible |  | 1 |  |  | 67.01 | 1 |  |  |  | 67.01
Microswitch | Acción rápida, palanca corta | 3 |  |  | 73.47 | 3 |  |  |  | 220.41
Placa perforada | Universal doble cara | 2 |  |  | 92 | 4 |  |  |  | 368
Módulo LM2596 | Ajustable, 12 V a 5 V | 1 |  |  | 242.05 | 1 |  |  |  | 242.05
Protoboard | 830 puntos | 1 |  |  | 270 | 1 |  |  |  | 270
Sensor angular AS5600 | 12 bits, I²C, con imán diametral | 1 |  |  |  |  | https://www.amazon.com/dp/B09KGWC1PT |  |  | 0
Celda de carga | Barra TAL220 o similar, 50 kg, 1 mV/V | 1 |  |  |  |  |  |  |  | 0
Motorreductor JGA25-370 | 12 V, 400 rpm, con encoder, par ≥ 0.8 kg·cm | 1 |  |  |  |  | https://www.amazon.com/-/es/gp/product/B08LD1JL8N/ref=sw_img_1?smid=A2SEQ57LRTT8C8&th=1 |  |  | 0
Módulo MPU6050 GY-521 | 6 ejes, I²C, suelto | 2 |  |  |  |  | https://www.amazon.com/-/es/gp/product/B0DTJY9B1D/ref=ewc_pr_img_4?smid=ABNC1ZV0O9ATN&psc=1 |  |  | 0
Fuente conmutada | 12 V, 3 A | 1 |  |  |  |  | https://www.amazon.com/-/es/gp/product/B07VQGHSWY/ref=ewc_pr_img_3?smid=AA0YO4F2UD50F&th=1 |  |  | 0
Buzzer pasivo | 5 V | 1 |  |  |  |  | https://www.amazon.com/-/es/gp/product/B0DYDN31PV/ref=ewc_pr_img_2?smid=A2F4WL24P91UAV&th=1 |  |  | 0
Estaño de soldadura | 0.8 mm con núcleo de resina | 1 rollo |  |  |  |  |  |  |  | 0
Insertos de latón M3 | Para impresión 3D | 20 |  |  |  |  |  |  |  | 0
Rodamientos | 686ZZ o bujes de bronce 6 mm | 4 |  |  |  |  |  |  |  | 0
Eje de acero | 6 mm × 100 mm | 1 |  |  |  |  |  |  |  | 0
Tornillería | M3, M4 y M5 con tuercas de nylon | 1 juego |  |  |  |  |  |  |  | 0
Filamento PLA+ | 1.75 mm, 1 kg | 2 |  |  |  |  |  |  |  | 0
 |  |  |  |  |  |  |  |  |  | 2557.39

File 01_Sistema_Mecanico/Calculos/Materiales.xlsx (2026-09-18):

Fecha: | 25/08/2026 - 03:26:59
Código | Código externo | Material | Última recepción | Cantidad | Precio total
MAT-0891 | CIN-0001 | Cintas Adhesivas Flex Profesional 1 | 2026-01-05T10:14:13.5496318 | 44 | 21100.2
MAT-0893 | CIN-0003 | Cintas Adhesivas Flex Estandar 3 | 2026-01-05T10:14:13.5498832 | 84 | 4626.72
MAT-0896 | CIN-0006 | Cintas Adhesivas Generico Estandar 6 | 2026-01-05T10:14:13.5498846 | 89 | 37670.14
MAT-0892 | CIN-0002 | Cintas Adhesivas Pro Estandar 2 | 2026-01-05T10:14:13.5498854 | 76 | 28692.28
 |  |  |  | Precio total: 92089.34
 |  |  |  | Monto impuesto: 11971.26
 |  |  |  | Monto total: 104060.59999999999

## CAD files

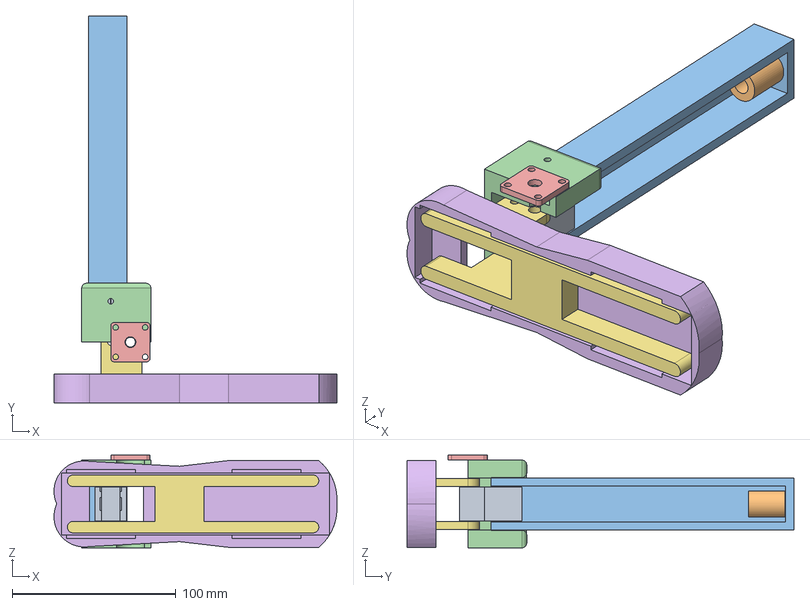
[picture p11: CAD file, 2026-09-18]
01_Sistema_Mecanico/Modelos_CAD/Tobillo_CL_Ensamble.step
172.8 x 236.0 x 56.6 mm

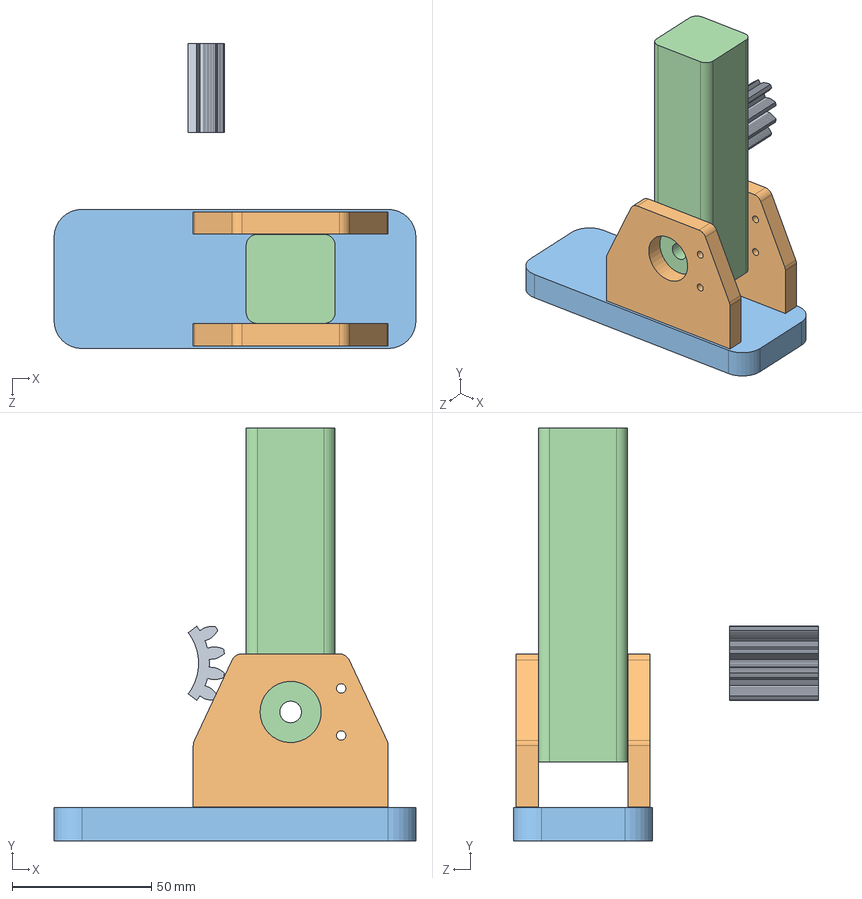
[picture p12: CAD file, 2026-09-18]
01_Sistema_Mecanico/Modelos_CAD/SolidWorks_Referencia/Ensamble Tobillo.SLDASM
130.0 x 148.4 x 109.6 mm
Tobillo-Columna_Tibial
Tobillo-Placa_Pie
Tobillo-Brazo_Horquilla x 2
Tobillo-Sector_Dentado

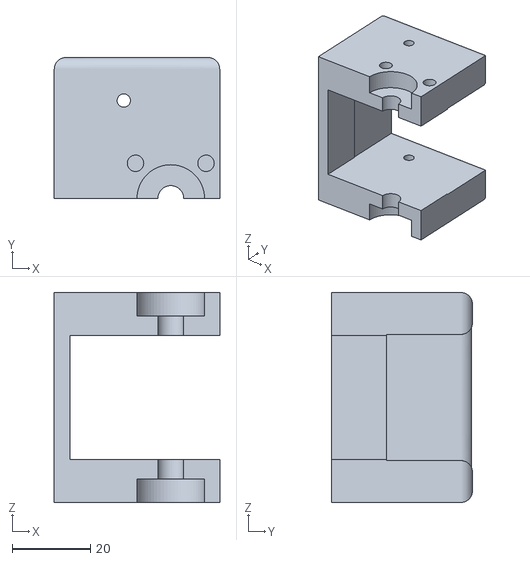
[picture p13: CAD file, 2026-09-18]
01_Sistema_Mecanico/Modelos_CAD/A3_soporte_tobillo_1.stl
42.2 x 36.0 x 53.6

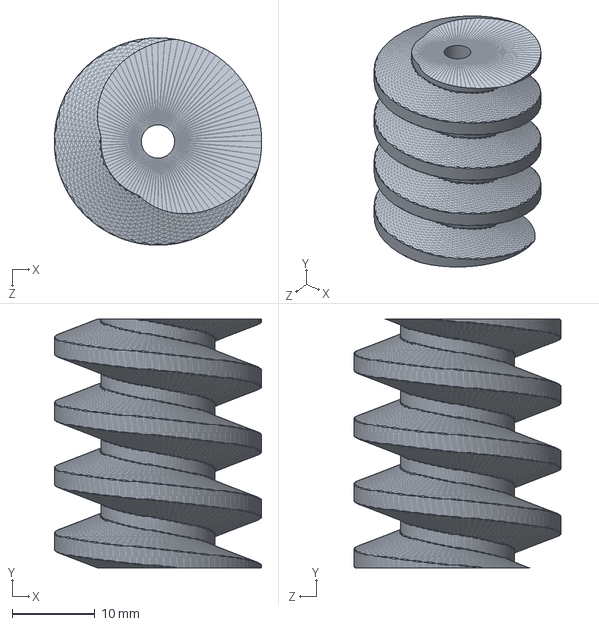
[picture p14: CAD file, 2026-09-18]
01_Sistema_Mecanico/Modelos_CAD/SolidWorks_Referencia/Tobillo-Sinfin.SLDPRT
25.0 x 30.0 x 25.0 mm

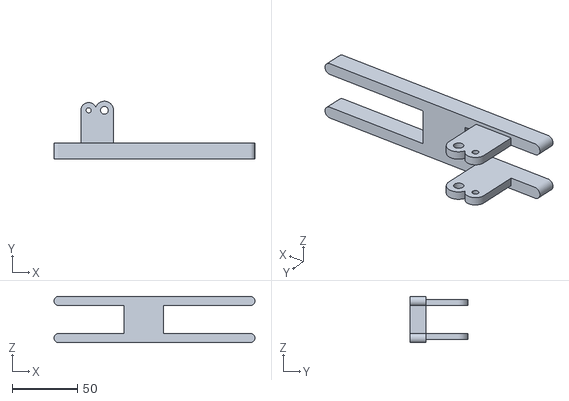
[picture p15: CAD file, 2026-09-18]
01_Sistema_Mecanico/Modelos_CAD/A5_placa_L_1.stl
153.5 x 44.0 x 35.3

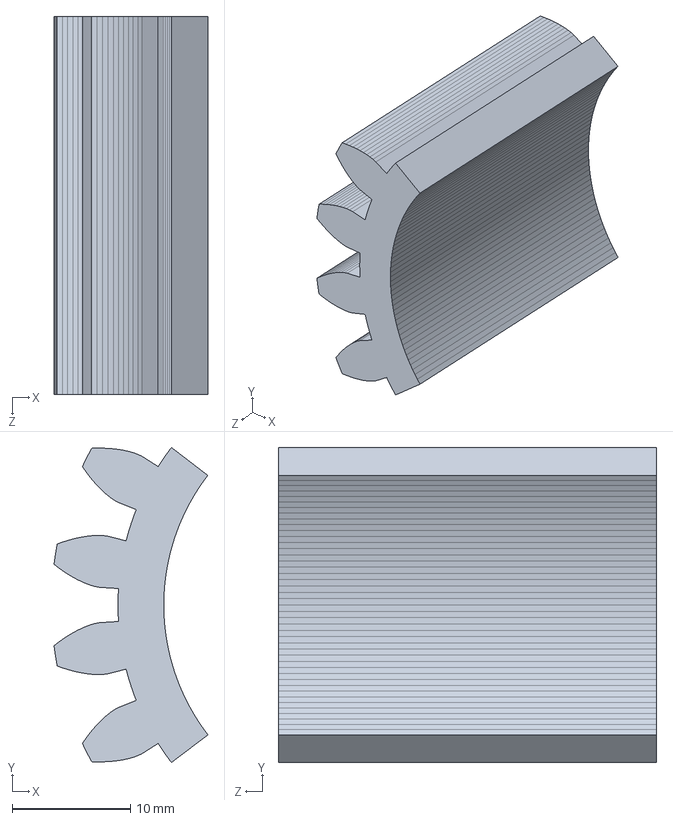
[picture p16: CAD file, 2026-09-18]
01_Sistema_Mecanico/Modelos_CAD/SolidWorks_Referencia/Tobillo-Sector_Dentado.SLDPRT
13.0 x 26.6 x 32.0 mm

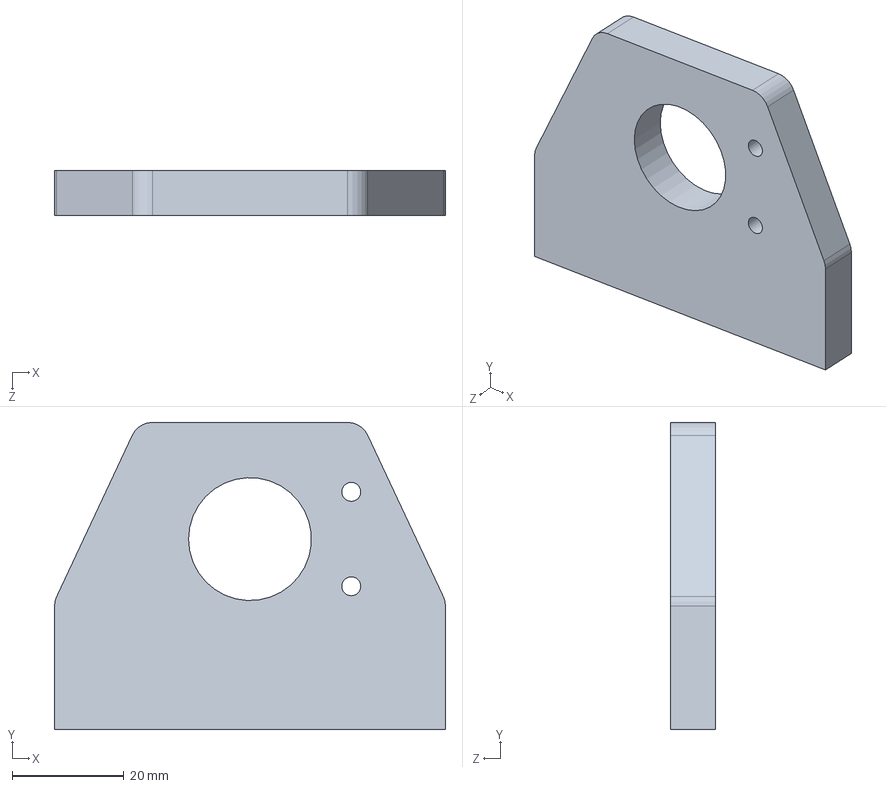
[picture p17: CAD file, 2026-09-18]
01_Sistema_Mecanico/Modelos_CAD/SolidWorks_Referencia/Tobillo-Brazo_Horquilla.SLDPRT
70.0 x 55.0 x 8.00 mm

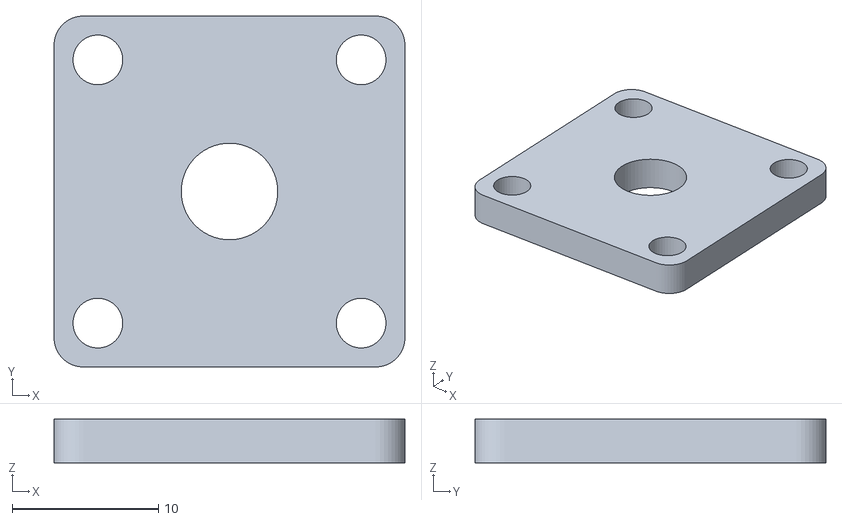
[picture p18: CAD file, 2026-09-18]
01_Sistema_Mecanico/Modelos_CAD/A3_placa_sensor_as5600_1.stl
24.0 x 24.0 x 3.00

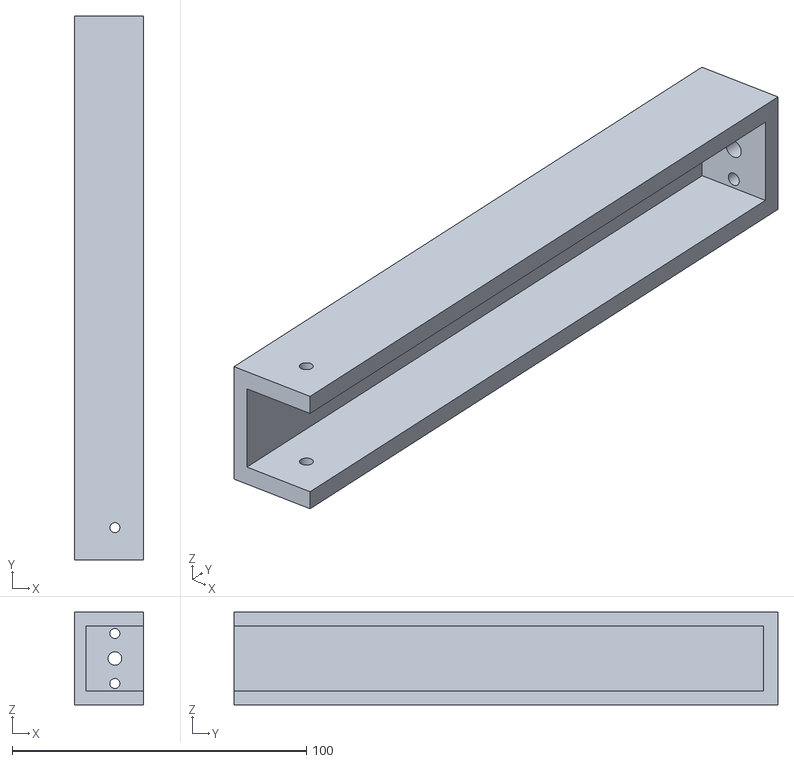
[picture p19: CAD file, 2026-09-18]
01_Sistema_Mecanico/Modelos_CAD/A2_columna_tibial_1.stl
23.5 x 185.0 x 31.6

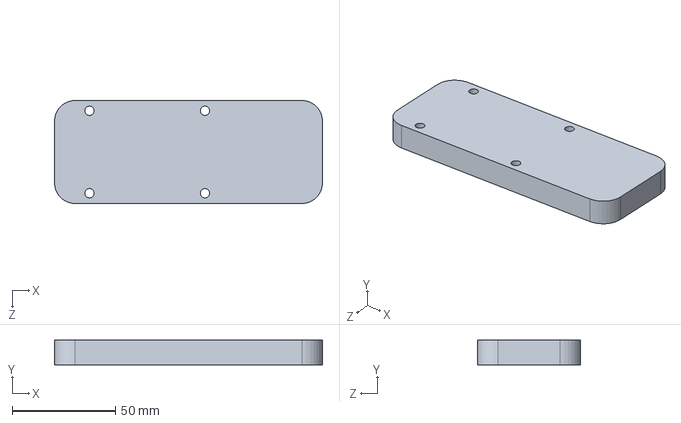
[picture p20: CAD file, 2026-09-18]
01_Sistema_Mecanico/Modelos_CAD/SolidWorks_Referencia/Tobillo-Placa_Pie.SLDPRT
130.0 x 12.0 x 50.0 mm

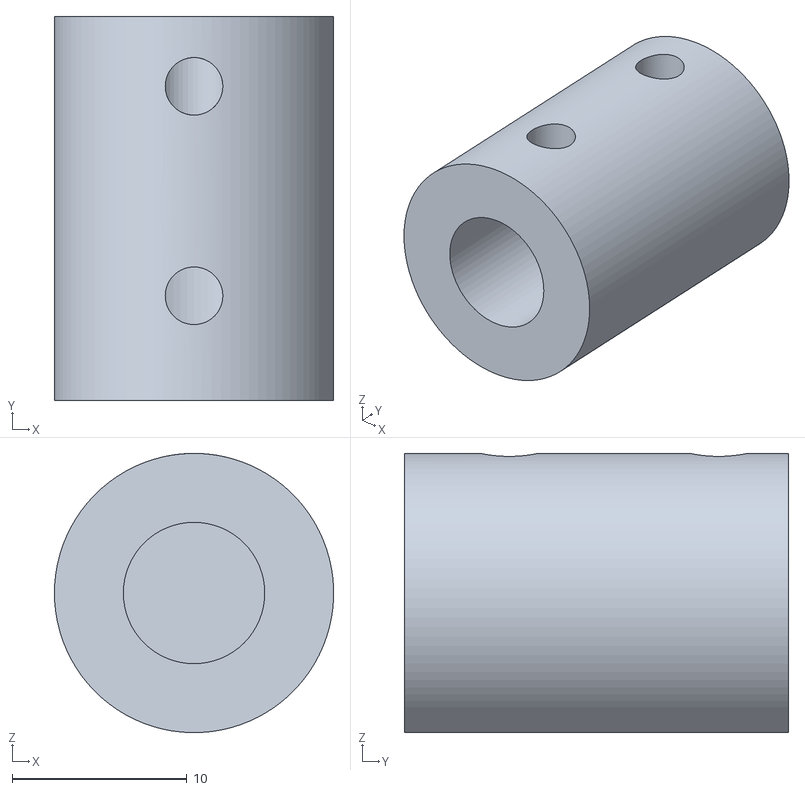
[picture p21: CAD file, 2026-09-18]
01_Sistema_Mecanico/Modelos_CAD/B7_acople_1.stl
16.0 x 22.0 x 16.0

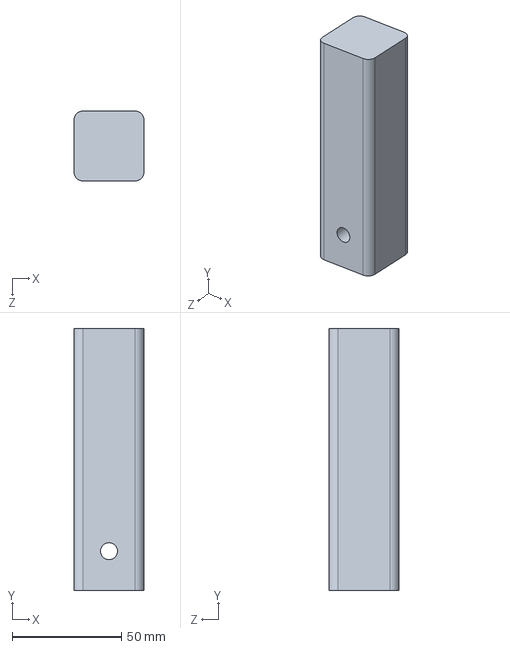
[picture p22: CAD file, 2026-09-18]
01_Sistema_Mecanico/Modelos_CAD/SolidWorks_Referencia/Tobillo-Columna_Tibial.SLDPRT
32.0 x 120.0 x 32.0 mm

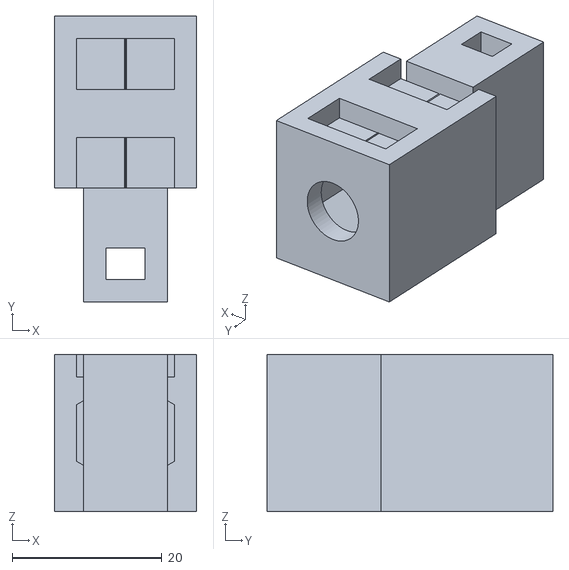
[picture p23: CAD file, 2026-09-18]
01_Sistema_Mecanico/Modelos_CAD/B3_horquilla_ranurada_1.stl
19.0 x 38.2 x 21.0

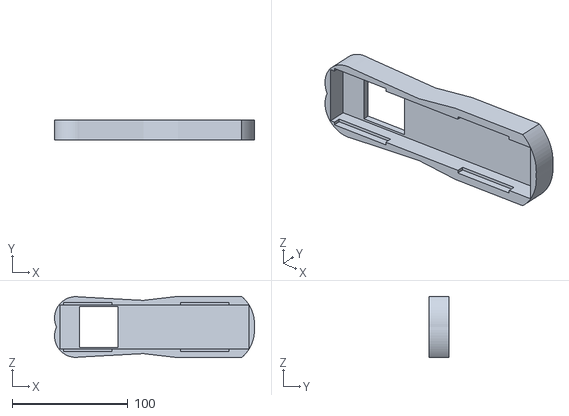
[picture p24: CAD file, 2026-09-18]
01_Sistema_Mecanico/Modelos_CAD/A5_cubierta_estetica_1.stl
172.8 x 17.5 x 53.0

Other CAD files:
01_Sistema_Mecanico/Modelos_CAD/Tobillo_CL.f3d

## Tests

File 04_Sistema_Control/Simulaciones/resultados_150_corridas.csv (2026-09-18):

ID_Corrida | Estrategia | Condicion_Inyectada | Clase_Emitida | Angulo_Alcanzado | Error_Angular | Tiempo_Respuesta_ms | Acierto
1 | Umbrales con Histeresis | -10.0 | -10 deg | -9.968 | 0.032 | 37.31 | 1
2 | Umbrales con Histeresis | -10.0 | -10 deg | -9.945 | 0.055 | 39.74 | 1
3 | Umbrales con Histeresis | -10.0 | -10 deg | -9.986 | 0.014 | 40.13 | 1
4 | Umbrales con Histeresis | -10.0 | -10 deg | -10.011 | 0.011 | 38.27 | 1
5 | Umbrales con Histeresis | -10.0 | -10 deg | -9.978 | 0.022 | 39.25 | 1
6 | Umbrales con Histeresis | -10.0 | -10 deg | -9.982 | 0.018 | 39.39 | 1
7 | Umbrales con Histeresis | -10.0 | -10 deg | -9.917 | 0.083 | 38.64 | 1
8 | Umbrales con Histeresis | -10.0 | -10 deg | -9.959 | 0.041 | 38.72 | 1
9 | Umbrales con Histeresis | -10.0 | -10 deg | -9.968 | 0.032 | 38.09 | 1
10 | Umbrales con Histeresis | -10.0 | -10 deg | -9.983 | 0.017 | 37.71 | 1
11 | Umbrales con Histeresis | -10.0 | -10 deg | -9.956 | 0.044 | 37.3 | 1
12 | Umbrales con Histeresis | -10.0 | -10 deg | -9.968 | 0.032 | 39.28 | 1
13 | Umbrales con Histeresis | -10.0 | -10 deg | -9.982 | 0.018 | 39.32 | 1
14 | Umbrales con Histeresis | -10.0 | -10 deg | -9.923 | 0.077 | 37.34 | 1
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

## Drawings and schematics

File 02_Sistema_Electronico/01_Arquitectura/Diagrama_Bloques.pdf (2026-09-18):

# DIAGRAMA DE ARQUITECTURA DEL SISTEMA ELECTRÓNICO Y CONTROL

## Prototipo Escalado de Tobillo Protésico Activo · ULSA León 2026

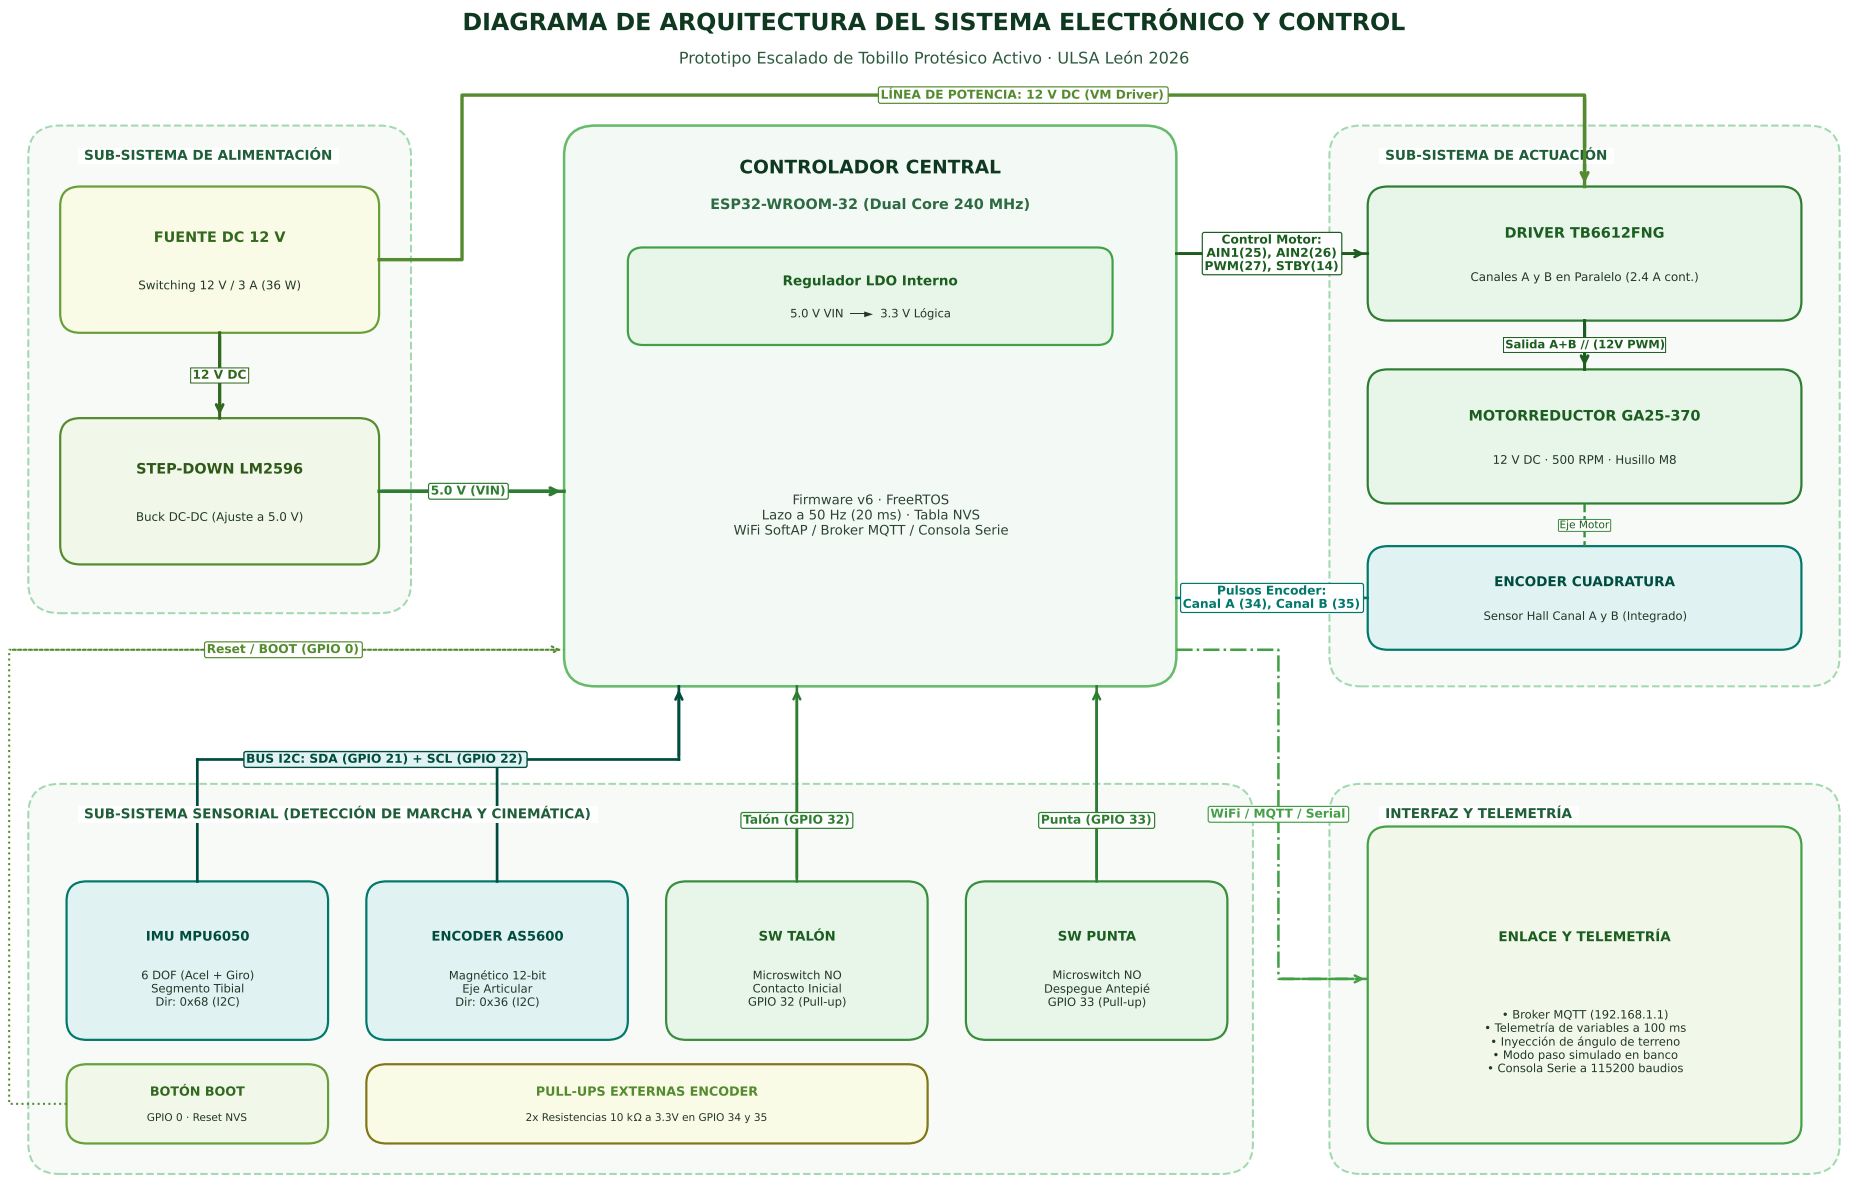
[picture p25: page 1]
SUB-SISTEMA DE ALIMENTACIÓN; CONTROLADOR CENTRAL; 5.0 V VIN; 3.3 V Lógica; SUB-SISTEMA SENSORIAL (DETECCIÓN DE MARCHA Y CINEMÁTICA); INTERFAZ Y TELEMETRÍA; FUENTE DC 12 V; Switching 12 V / 3 A (36 W); STEP-DOWN LM2596; DRIVER TB6612FNG; MOTORREDUCTOR GA25-370; ENCODER CUADRATURA; IMU MPU6050; ENCODER AS5600; Magnético 12-bit Eje Articular Dir: 0x36 (I2C); SW TALÓN; SW PUNTA; BOTÓN BOOT; 2x Resistencias 10 k; a 3.3V en GPIO 34 y 35; ENLACE Y TELEMETRÍA; 5.0 V (VIN)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

LÍNEA DE POTENCIA: 12 V DC (VM Driver)

SUB-SISTEMA DE ACTUACIÓN

ESP32-WROOM-32 (Dual Core 240 MHz)

Regulador LDO Interno

Canales A y B en Paralelo (2.4 A cont.)

12 V DC · 500 RPM · Husillo M8

Firmware v6 · FreeRTOS
Lazo a 50 Hz (20 ms) · Tabla NVS
WiFi SoftAP / Broker MQTT / Consola Serie

Buck DC-DC (Ajuste a 5.0 V)

Sensor Hall Canal A y B (Integrado)

Reset / BOOT (GPIO 0)

WiFi / MQTT / Serial

6 DOF (Acel + Giro)
Segmento Tibial
Dir: 0x68 (I2C)

Microswitch NO
Contacto Inicial
GPIO 32 (Pull-up)

Despegue Antepié
GPIO 33 (Pull-up)

Broker MQTT (192.168.1.1)
Telemetría de variables a 100 ms
Inyección de ángulo de terreno
Modo paso simulado en banco
Consola Serie a 115200 baudios

PULL-UPS EXTERNAS ENCODER

GPIO 0 · Reset NVS

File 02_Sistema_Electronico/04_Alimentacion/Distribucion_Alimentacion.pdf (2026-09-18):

# MAPA DE DISTRIBUCIÓN DE ENERGÍA Y GESTIÓN DE TIERRAS (GND)

Topología en Estrella · Separación de Dominios de Potencia y Señal Lógica · ULSA León 2026

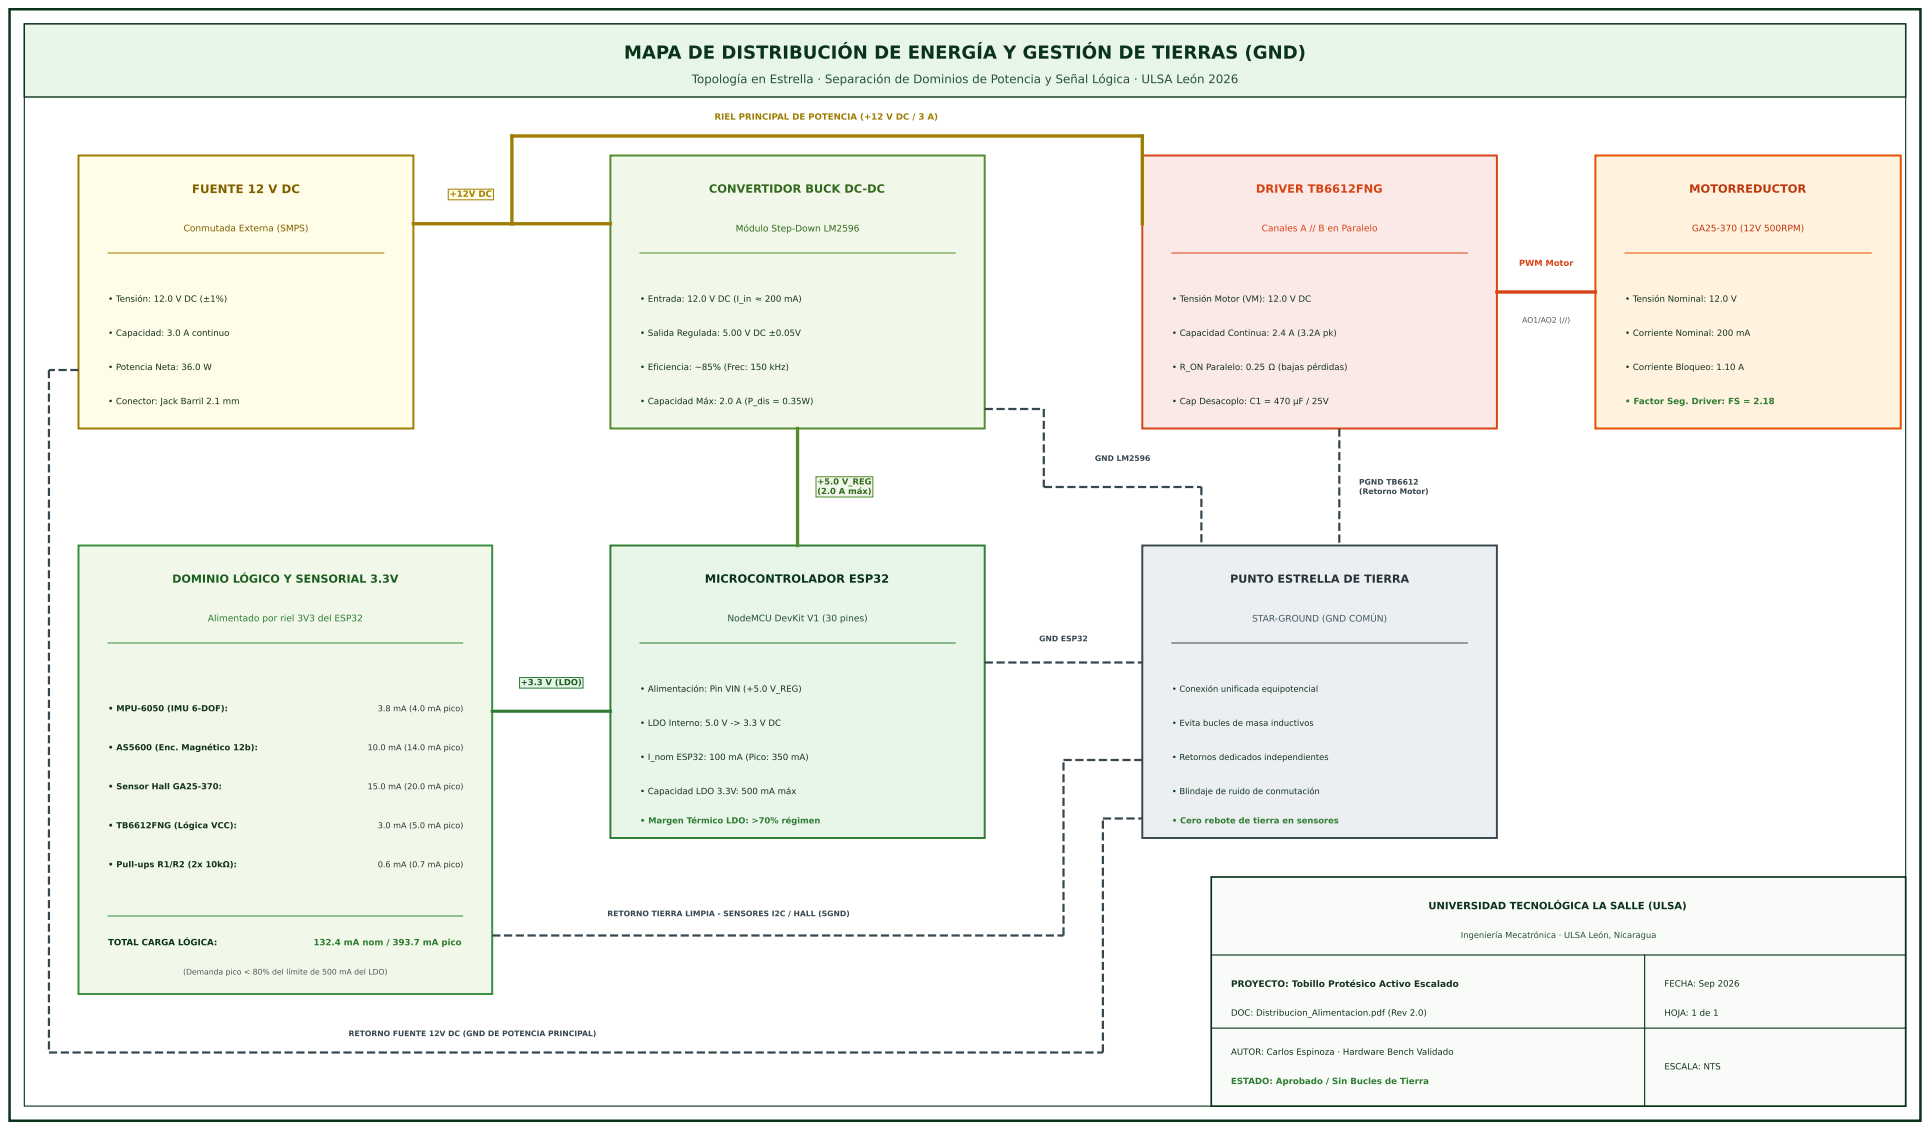
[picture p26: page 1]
FECHA: Sep 2026; HOJA: 1 de 1; ESCALA: NTS; FUENTE 12 V DC; Tensión: 12.0 V DC (±1%); Capacidad: 3.0 A continuo; Potencia Neta: 36.0 W; Entrada: 12.0 V DC (I_in; Capacidad Máx: 2.0 A (P_dis = 0.35W); MICROCONTROLADOR ESP32; MPU-6050 (IMU 6-DOF):; 3.8 mA (4.0 mA pico); AS5600 (Enc. Magnético 12b):; 10.0 mA (14.0 mA pico); Sensor Hall GA25-370:; 15.0 mA (20.0 mA pico); TB6612FNG (Lógica VCC):; 3.0 mA (5.0 mA pico); Pull-ups R1/R2 (2x 10k ):; 0.6 mA (0.7 mA pico); TOTAL CARGA LÓGICA: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

RIEL PRINCIPAL DE POTENCIA (+12 V DC / 3 A)

CONVERTIDOR BUCK DC-DC

Conmutada Externa (SMPS)

Módulo Step-Down LM2596

Canales A // B en Paralelo

Tensión Motor (VM): 12.0 V DC

Salida Regulada: 5.00 V DC ±0.05V

Capacidad Continua: 2.4 A (3.2A pk)

Corriente Nominal: 200 mA

Eficiencia: ~85% (Frec: 150 kHz)

Conector: Jack Barril 2.1 mm

Cap Desacoplo: C1 = 470 µF / 25V

Factor Seg. Driver: FS = 2.18

DOMINIO LÓGICO Y SENSORIAL 3.3V

PUNTO ESTRELLA DE TIERRA

Alimentado por riel 3V3 del ESP32

NodeMCU DevKit V1 (30 pines)

STAR-GROUND (GND COMÚN)

Alimentación: Pin VIN (+5.0 V_REG)

Conexión unificada equipotencial

LDO Interno: 5.0 V -> 3.3 V DC

Evita bucles de masa inductivos

I_nom ESP32: 100 mA (Pico: 350 mA)

Retornos dedicados independientes

Capacidad LDO 3.3V: 500 mA máx

Blindaje de ruido de conmutación

Margen Térmico LDO: >70% régimen

Cero rebote de tierra en sensores

UNIVERSIDAD TECNOLÓGICA LA SALLE (ULSA)

RETORNO TIERRA LIMPIA - SENSORES I2C / HALL (SGND)

Ingeniería Mecatrónica · ULSA León, Nicaragua

(Demanda pico < 80% del límite de 500 mA del LDO)

PROYECTO: Tobillo Protésico Activo Escalado

DOC: Distribucion_Alimentacion.pdf (Rev 2.0)

RETORNO FUENTE 12V DC (GND DE POTENCIA PRINCIPAL)

AUTOR: Carlos Espinoza · Hardware Bench Validado

ESTADO: Aprobado / Sin Bucles de Tierra

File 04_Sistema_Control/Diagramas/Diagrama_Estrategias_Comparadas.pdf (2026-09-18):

# ARQUITECTURA COMPARATIVA DE CLASIFICACIÓN DE TERRENO

### Estrategia A (Umbrales con Histéresis) vs. Estrategia B (Lógica Difusa) · ULSA León 2026

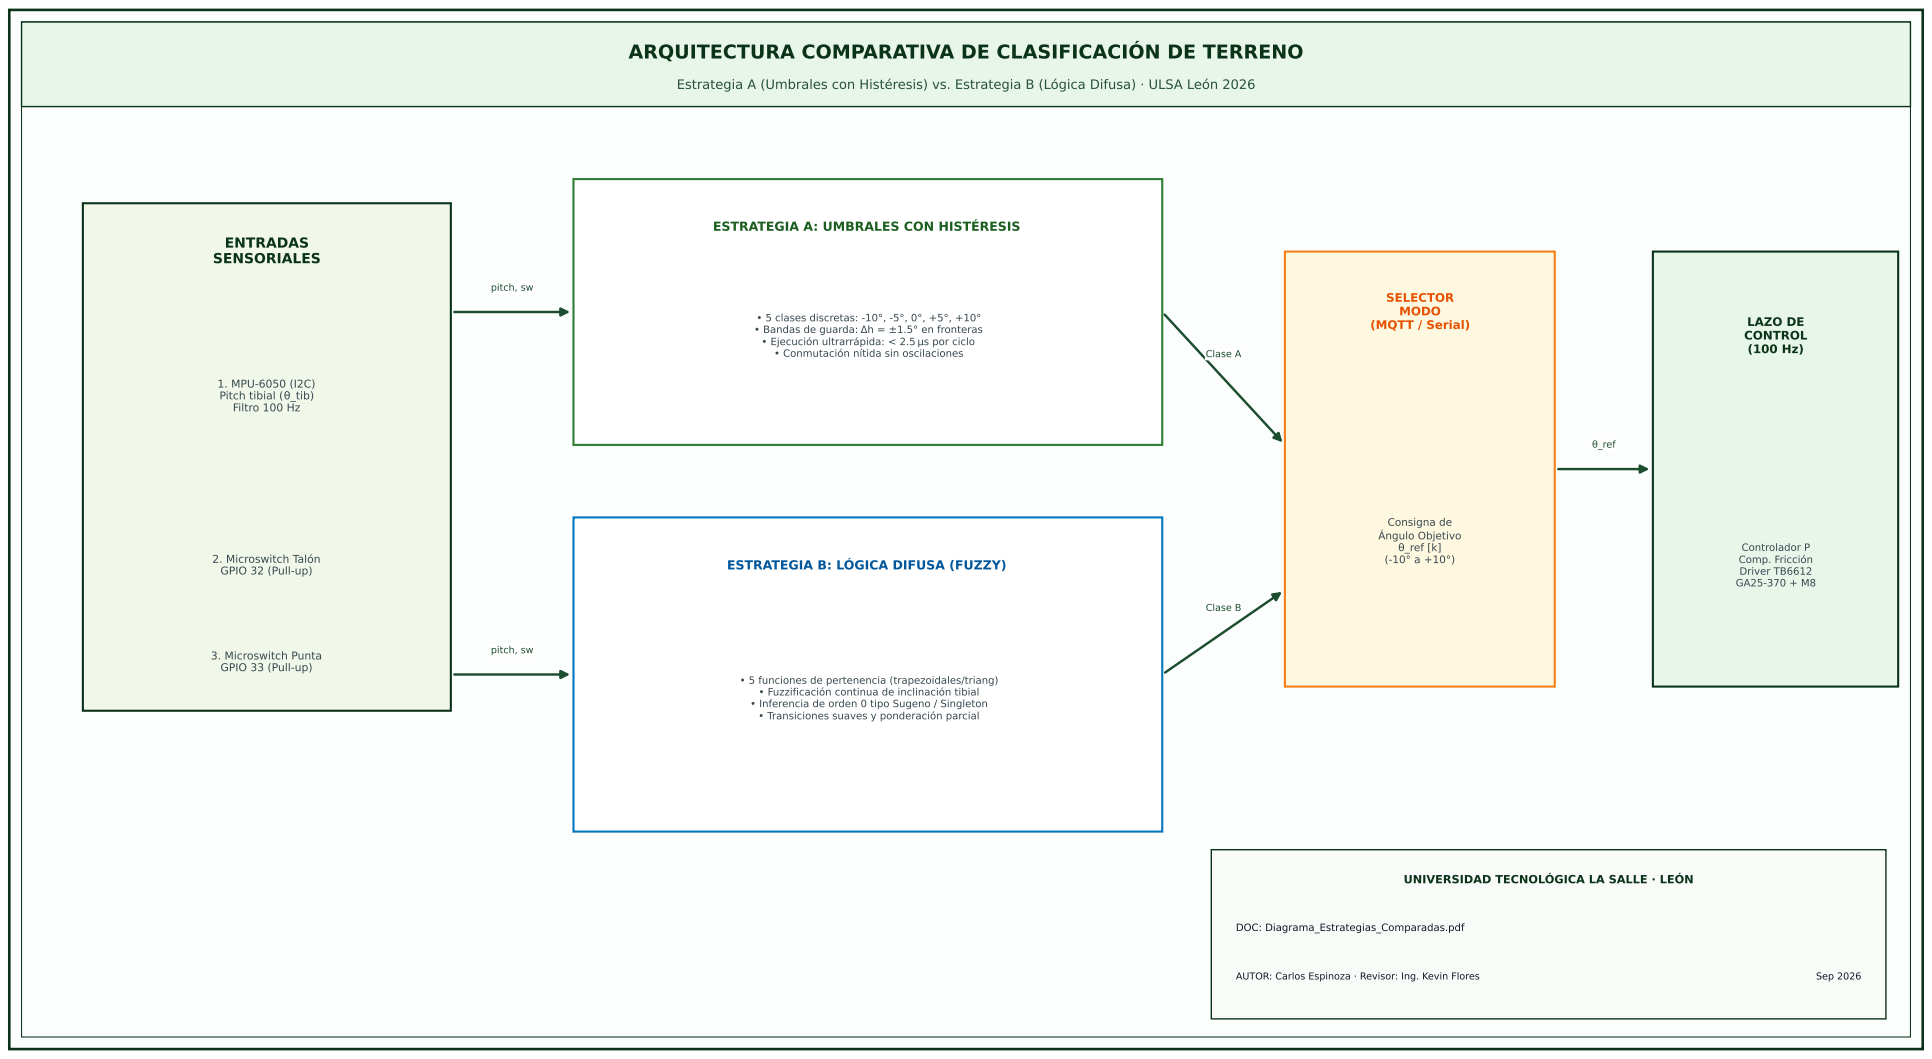
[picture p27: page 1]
ENTRADAS SENSORIALES; 1. MPU-6050 (I2C) Pitch tibial ( _tib) Filtro 100 Hz; SELECTOR MODO (MQTT / Serial); Consigna de Ángulo Objetivo _ref [k] (-10° a +10°); LAZO DE CONTROL (100 Hz); Controlador P Comp. Fricción Driver TB6612 GA25-370 + M8; pitch, sw; Clase A; Clase B; _ref; DOC: Diagrama_Estrategias_Comparadas.pdf; AUTOR: Carlos Espinoza · Revisor: Ing. Kevin Flores; Sep 2026

ESTRATEGIA A: UMBRALES CON HISTÉRESIS

5 clases discretas: -10°, -5°, 0°, +5°, +10°
Bandas de guarda: h = ±1.5° en fronteras
Ejecución ultrarrápida: < 2.5 s por ciclo
Conmutación nítida sin oscilaciones

2. Microswitch Talón
GPIO 32 (Pull-up)

ESTRATEGIA B: LÓGICA DIFUSA (FUZZY)

3. Microswitch Punta
GPIO 33 (Pull-up)

5 funciones de pertenencia (trapezoidales/triang)
Fuzzificación continua de inclinación tibial
Inferencia de orden 0 tipo Sugeno / Singleton
Transiciones suaves y ponderación parcial

UNIVERSIDAD TECNOLÓGICA LA SALLE · LEÓN

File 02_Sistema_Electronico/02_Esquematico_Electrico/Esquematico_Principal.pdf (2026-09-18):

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

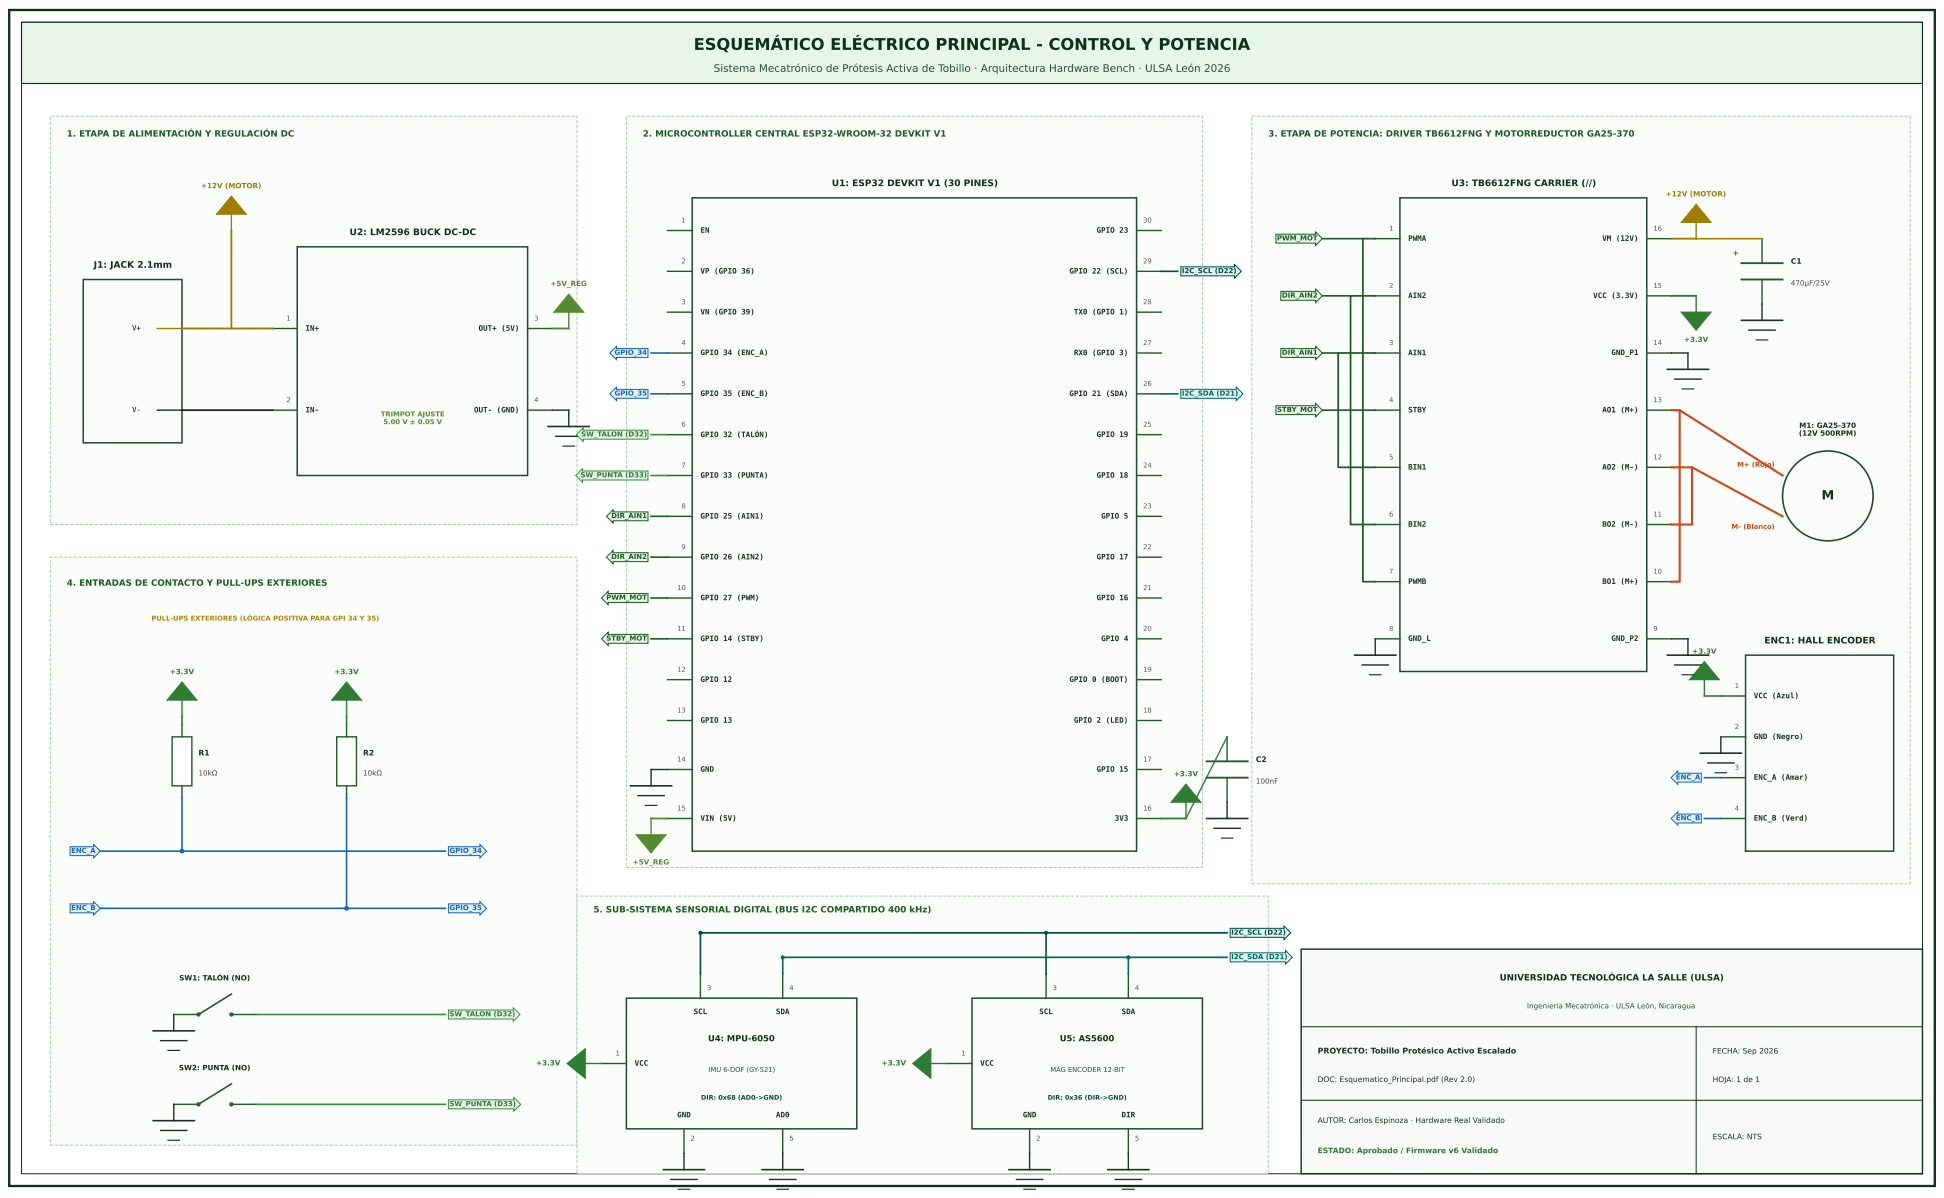
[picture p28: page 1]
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

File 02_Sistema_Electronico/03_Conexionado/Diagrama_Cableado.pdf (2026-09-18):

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

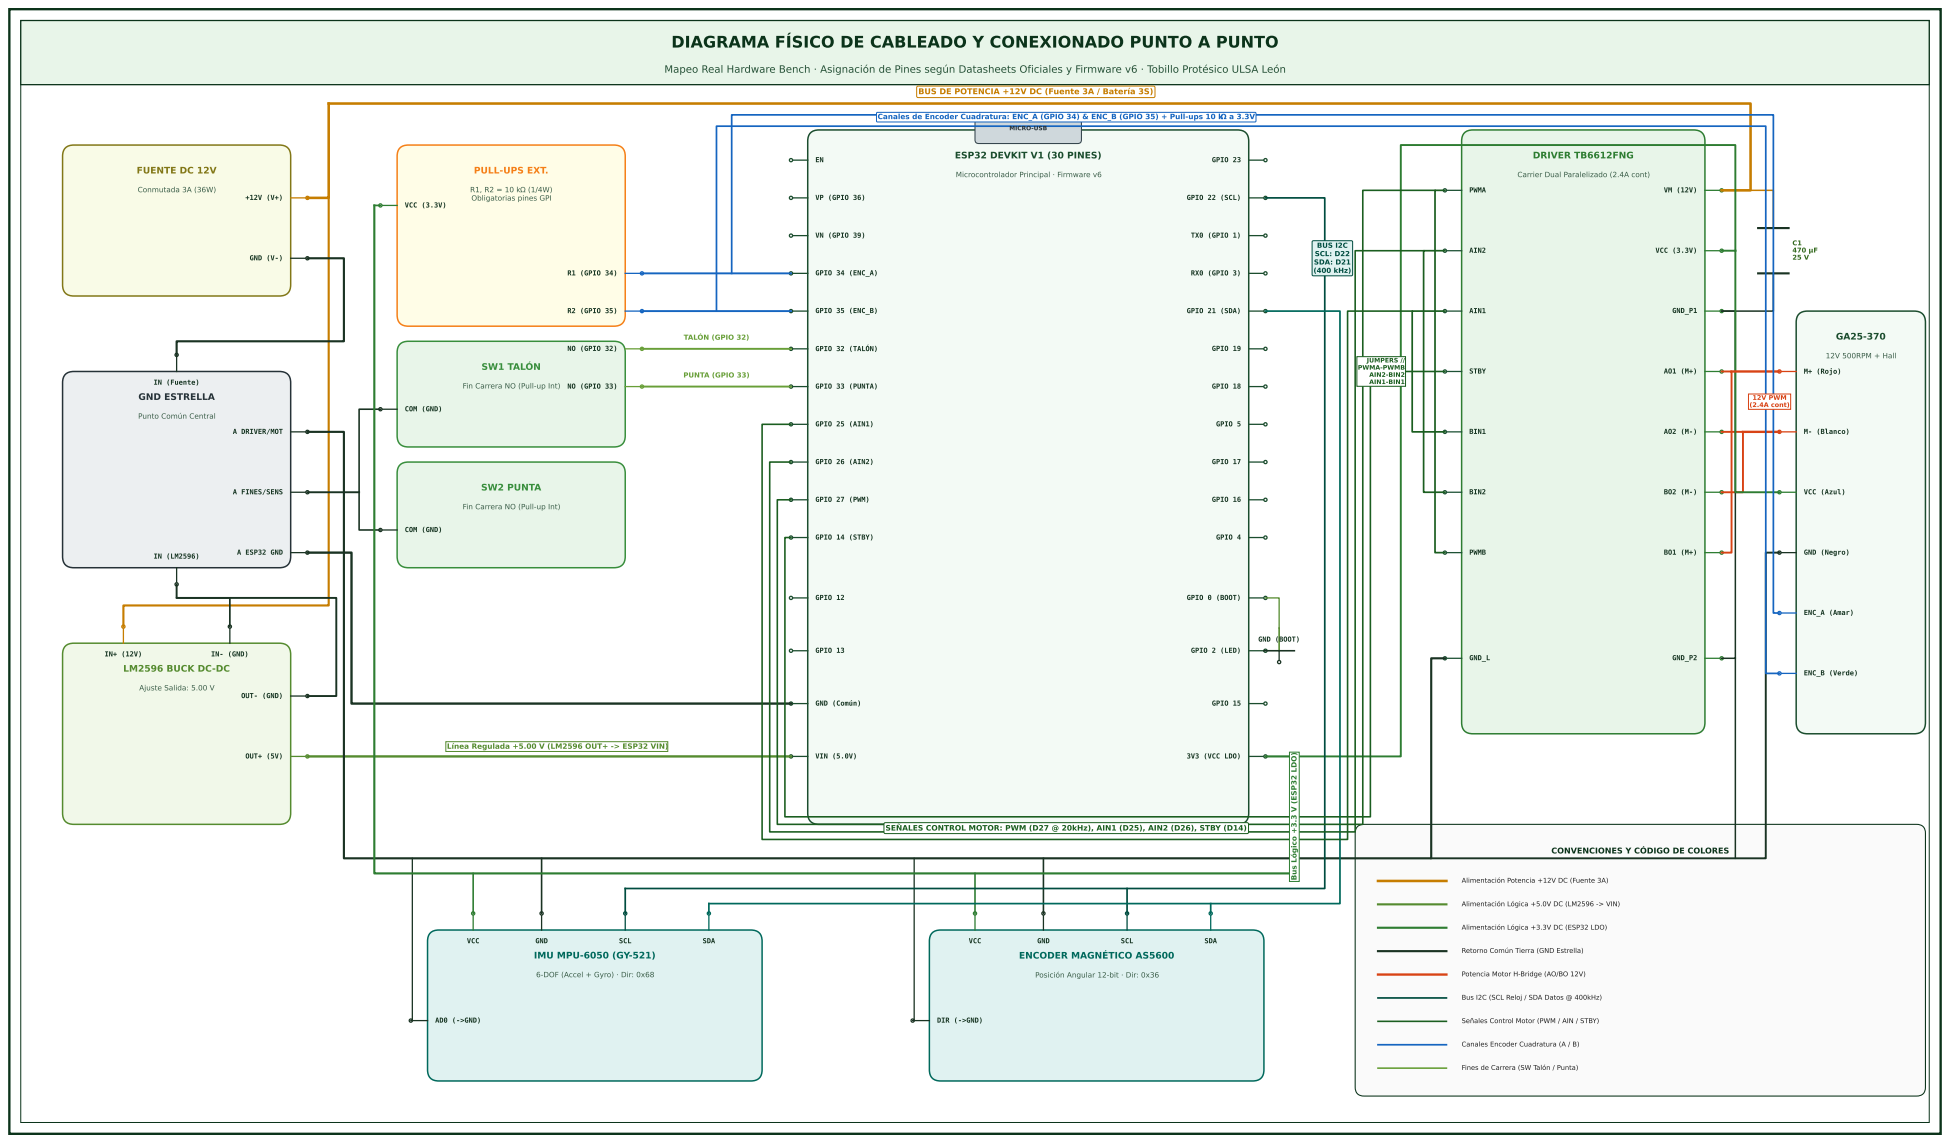
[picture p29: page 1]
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

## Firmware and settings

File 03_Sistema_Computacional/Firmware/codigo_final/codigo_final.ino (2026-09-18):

/*
  Tobillo protesico activo - firmware v6

  ESP32, GA25-370 con encoder integrado, AS5600, MPU6050, 2 microswitches,
  TB6612FNG con canales A y B en paralelo.

  Posicion angular: contador de pulsos del encoder. Tabla de 5 puntos
  (-30, -15, 0, +15, +30) con interpolacion lineal por tramo.
  AS5600: verificacion cruzada por magnitud de campo, no realimentacion.
  Configuracion y tabla en NVS, se cambian por comando sin reflashear.

  Requisitos de hardware:
    - Acople eje-husillo con prisionero o pasador. Si patina, el encoder
      cuenta y la articulacion no se mueve, y el error sobrevive al apagado.
    - Pull-ups de 10k en GPIO34 y GPIO35: son entrada pura, sin pull-up interna.

  Tres modos de operacion:
    - Sensores: el terreno sale de la inclinacion tibial menos el angulo de
      articulacion, promediado durante la fase de apoyo plano.
    - Terreno inyectado: el valor llega por MQTT o serial y el lazo hace una
      correccion punto a punto. Clasificadores identicos al modo anterior.
    - Paso simulado: un secuenciador recorre las ocho subfases del ciclo de
      marcha sobre una base de tiempo estirada y el tobillo sigue la
      trayectoria angular completa, apoyo incluido. Solo para banco, sin
      carga: no difiere el movimiento por contacto.

  Convencion de signo: dorsiflexion positiva, plantiflexion negativa.

  Comandos por serial o por MQTT. '?' para la lista.
*/

#include <WiFiManager.h>
#include <PubSubClient.h>
#include <WiFi.h>
#include <Preferences.h>
#include <Wire.h>
#include <ArduinoJson.h>
#include <math.h>
#include <string.h>

// --- Pines ---

#define SDA_PIN 21
#define SCL_PIN 22
#define AS5600_ADDR 0x36
#define MPU6050_ADDR 0x68

#define REG_RAW_ANGLE_H 0x0C
#define REG_MAGNITUDE_H 0x1B
#define REG_AGC 0x1A

#define BOTON_RESET 0
#define TIEMPO_RESET_MS 3000

#define PIN_TALON 32
#define PIN_PUNTA 33
#define DEBOUNCE_MS 35

#define PIN_ENC_A 34
#define PIN_ENC_B 35

#define PIN_AIN1 25
#define PIN_AIN2 26
#define PIN_PWM 27
#define PIN_STBY 14

#define PWM_FREQ 20000
#define PWM_RES 8

// Invertir si el mecanismo se mueve al reves de lo pedido.
#define SIGNO_MOTOR 1

// 0 = flancos de subida de A. 1 = ambos flancos de A, duplica los pulsos
// por grado y obliga a recalibrar la tabla.
#define DECODIF_2X 0

// --- Red ---

#define PREFS_NAMESPACE "tobillo"
#define PREFS_KEY_BROKER "brokerIp"
#define PREFS_KEY_TABLA "tablaPul"
#define PREFS_KEY_ANGULO "angUlt"
#define PREFS_KEY_PULSOS "pulsUlt"
#define PREFS_KEY_LIMPIO "cierreOk"
#define PREFS_KEY_PWMMIN "pwmMin"
#define PREFS_KEY_KP "kp"
#define PREFS_KEY_SALIDA "extSalida"
#define PREFS_KEY_TERRENO "sgTerreno"
#define PREFS_KEY_GANANCIA "ganObj"
#define PREFS_KEY_CICLO "msCiclo"
#define PREFS_KEY_AMPLITUD "amplPaso"

#define MQTT_PORT 1883
#define MQTT_CLIENT_ID "tobilloESP32"
#define MQTT_RETRY_MS 5000
#define MQTT_BUFFER 2560

#define TOPIC_ESTADO "tobillo/estado"
#define TOPIC_COMANDO "tobillo/comando"
#define TOPIC_TERRENO "tobillo/terreno"
#define TOPIC_TELEMETRIA "tobillo/telemetria"
#define TOPIC_CICLO "tobillo/ciclo"
#define TOPIC_PASO "tobillo/paso"
#define TOPIC_LOG "tobillo/log"

// --- Control ---

#define PWM_KICK 255
#define KICK_MAX_MS 150
#define MOV_CONFIRMA_PULSOS 8         // ~0.3 deg a 26 pulsos/grado
#define PWM_MAX 200
#define MS_FRENO 40
#define CONTROL_MS 20

#define ZONA_MUERTA_CFG 2.0           // inercia tras el freno: ~0.8 deg
#define PULSOS_ZONA_MUERTA 3
#define TICKS_ASENTADO 3
#define MAX_INVERSIONES 2

#define TIMEOUT_AJUSTE_MS 1200
#define TIMEOUT_TOTAL_MS 8000
#define STALL_MS 200
#define STALL_PULSOS 10               // < 2 deg/s en ventana de 200 ms
#define ENFRIAMIENTO_MS 2000
#define MAX_BLOQUEOS 3

// Al alcanzar MAX_BLOQUEOS el sistema se libera solo tras esta espera, mas
// larga que el enfriamiento normal. Si hace falta varias veces seguidas sin
// un movimiento exitoso en medio, deja de liberarse: eso ya no es un falso
// positivo, es algo mecanico que hay que revisar a mano.
#define ENFRIAMIENTO_LIMITE_MS 5000
#define MAX_AUTOLIBERAR 3

#define LIMITE_ANGULO 30.0
#define MARGEN_PULSOS 25              // ~1 deg mas alla del limite
#define JOG_MAX_GRADOS 5.0
#define PULSOS_POR_GRADO_NOMINAL 26.0 // medido con inclinometro: ~25.7
#define JOG_MS 1500
#define TOPE_MAX_INTENTOS 40

// --- Verificacion cruzada ---

#define DISCREPANCIA_MAX 8.0
#define VERIFICACION_MS 500
#define MAGNITUD_MINIMA 10
#define DERIVA_AGC 40
#define N_PROM_MAG 6
#define RANGO_VERIFICACION 15.0       // la curva de magnitud llega hasta 15 deg
#define SENS_MIN_MAG 0.8              // unidades de magnitud por grado
#define ZONA_CIEGA_VERIF 5.0          // cerca del cero la curva es plana

// --- Terreno ---

#define EJE_SAGITAL 2
#define SIGNO_TIBIA 1.0
#define OFFSET_TIBIA 0.0
#define RETARDO_ESTABILIZACION_MS 30
#define MIN_MUESTRAS_PLANO 2
#define TOLERANCIA_GRAVEDAD 0.35      // relajado para manipulacion manual

// --- Simulacion de terreno ---

#define LIMITE_TERRENO_SIM 30.0
#define SERIE_MAX 12
#define SERIE_PAUSA_MS 1500

// --- Paso simulado ---

// El ciclo humano dura ~1.1 s. El prebalanceo pide del orden de 270 deg/s
// y el mecanismo da unos 35, asi que la base de tiempo va estirada. Esto
// reproduce la forma de la trayectoria y la secuencia de subfases, no la
// dinamica de la marcha real.
#define MS_CICLO_MIN 1000
#define MS_CICLO_MAX 10000
#define MS_CICLO_DEFECTO 4000

#define AMPLITUD_MIN 0.2
#define AMPLITUD_MAX 1.2

#define ZONA_SEGUIMIENTO 1.0          // banda sin actuacion en seguimiento
#define PAUSA_PASOS_MS 800
#define PASO_RESUMEN_MS 120

// Reintentos mientras el sistema se libera solo, para que un bloqueo
// transitorio no mate una caminata entera.
#define REINTENTO_CAMINATA_MS 1000
#define MAX_REINTENTOS_CAMINATA 12

// --- Clasificadores ---

#define N_CLASES 5
#define HISTERESIS 1.5
#define FUZZY_ANCHO 7.5

#define TELEMETRIA_MS 100
#define VEL_VENTANA_MS 100

// --- Tabla de posicion ---

// La interpolacion lineal entre puntos deja del orden de 0.5 a 1 deg de
// error en el medio de cada tramo, por la curvatura del eslabonamiento.
#define N_REF 5
#define IDX_CERO 2
const float refAngulos[N_REF] = {-30, -15, 0, 15, 30};

long refPulsos[N_REF] = {0, 0, 0, 0, 0};
bool tablaValida = false;

// Magnitud de campo del AS5600 contra valor absoluto del angulo. Monotona
// decreciente en cada rama. Solo para verificacion cruzada.
#define N_MAG 7
const float magAbsAngulo[N_MAG] = {0, 3, 5, 8, 10, 12, 15};
const float magRamaPos[N_MAG]   = {41.6, 39.4, 36.6, 32.7, 28.3, 24.6, 21.2};
const float magRamaNeg[N_MAG]   = {41.6, 41.5, 39.7, 37.3, 33.9, 30.8, 26.4};

// --- Trayectoria del ciclo de marcha ---

// Subfases segun la terminologia de Rancho Los Amigos, como fraccion del
// ciclo medido de contacto de talon a contacto del mismo talon.
// Apoyo 0 a 60 por ciento, balanceo 60 a 100.
#define PCT_RESP_CARGA 0.10
#define PCT_MEDIO_APOYO 0.30
#define PCT_APOYO_TERM 0.50
#define PCT_DESPEGUE 0.60
#define PCT_BAL_INICIAL 0.73
#define PCT_MEDIO_BAL 0.87

// Puntos de la trayectoria angular del tobillo. Dorsiflexion positiva.
// Neutro al contacto, plantiflexion en la respuesta de carga, dorsiflexion
// creciente pasado el medio apoyo con maximo antes del contacto opuesto,
// plantiflexion rapida en el despegue y vuelta a neutro en el balanceo.
// Interpolacion lineal entre puntos: aproxima la forma, no la curva exacta.
#define N_TRAY 8
const float trayPct[N_TRAY] = {0.00, 0.08, 0.30, 0.48, 0.60, 0.75, 0.87, 1.00};
const float trayAng[N_TRAY] = {0.0, -5.0,  2.0,  9.0, -14.0, -4.0,  0.0,  0.0};

// --- Configuracion persistente ---

int pwmMin = 110;              // duty minimo de sostenimiento
float kpControl = 1.2;         // duty por grado de error
int extremoSalida = 1;         // lado donde el husillo sale de la tuerca
float signoTerreno = 1.0;      // convencion de compensacion
float gananciaObjetivo = 1.0;  // multiplica la salida del clasificador
unsigned long msCicloPaso = MS_CICLO_DEFECTO;
float amplitudPaso = 0.80;     // escala la trayectoria de marcha
int dutyJog = 140;             // velocidad de los jogs, no se guarda

// --- Estado de red ---

Preferences prefs;
char brokerIp[16] = "192.168.1.1";

WiFiClient wifiClient;
PubSubClient mqttClient(wifiClient);
bool wifiHabilitado = false;
bool telemetriaContinua = true;

// --- Consola con espejo en MQTT ---

// Las lineas impresas se encolan y se publican desde loop(), nunca desde
// dentro de un print, para no meter latencia de red en el lazo de control.

#define LOG_LINEAS 12
#define LOG_LARGO 160

class ConsolaMqtt : public Stream {
  HardwareSerial* hw;
  char cola[LOG_LINEAS][LOG_LARGO];
  int entrada = 0;
  int salida = 0;
  int largoActual = 0;

public:
  ConsolaMqtt(HardwareSerial* p) : hw(p) { cola[0][0] = '\0'; }

  void begin(unsigned long baud) { hw->begin(baud); }

  int available() override { return hw->available(); }
  int read() override { return hw->read(); }
  int peek() override { return hw->peek(); }
  void flush() override { hw->flush(); }

  size_t write(uint8_t c) override {
    hw->write(c);
    if (c == '\r') return 1;
    if (c == '\n') { cerrarLinea(); return 1; }
    if (largoActual < LOG_LARGO - 1) {
      cola[entrada][largoActual++] = (char)c;
    } else {
      cerrarLinea();
      cola[entrada][largoActual++] = (char)c;
    }
    return 1;
  }

  size_t write(const uint8_t* b, size_t n) override {
    for (size_t i = 0; i < n; i++) write(b[i]);
    return n;
  }

  void cerrarLinea() {
    if (largoActual == 0) return;
    cola[entrada][largoActual] = '\0';
    largoActual = 0;
    int siguienteIdx = (entrada + 1) % LOG_LINEAS;
    if (siguienteIdx == salida) salida = (salida + 1) % LOG_LINEAS;
    entrada = siguienteIdx;
  }

  bool pendiente() { return entrada != salida; }

  const char* sacarLinea() {
    if (entrada == salida) return NULL;
    const char* p = cola[salida];
    salida = (salida + 1) % LOG_LINEAS;
    return p;
  }

  void descartar() { salida = entrada; }
};

ConsolaMqtt Consola(&Serial);
#define Serial Consola

unsigned long ultimoIntentoMqtt = 0;
unsigned long ultimaTelemetria = 0;
unsigned long ultimoControl = 0;
unsigned long ultimaVerificacion = 0;

// --- Encoder ---

volatile long pulsosEncoder = 0;

void IRAM_ATTR isrEncoder() {
#if DECODIF_2X
  if (digitalRead(PIN_ENC_A) == digitalRead(PIN_ENC_B)) pulsosEncoder--;
  else pulsosEncoder++;
#else
  if (digitalRead(PIN_ENC_B)) pulsosEncoder++;
  else pulsosEncoder--;
#endif
}

// --- Posicion ---

float anguloArticulacion = 0.0;
bool posicionConfiable = false;
bool fueraDeTabla = false;

float velAngular = 0.0;        // deg/s de la articulacion, con signo
float velPulsosSeg = 0.0;      // pulsos/s del encoder, con signo
long pulsosVentana = 0;
float anguloVentana = 0.0;
unsigned long tVentanaVel = 0;

// --- AS5600 ---

float bufMagnitud[N_PROM_MAG];
int idxMag = 0;
bool magLleno = false;
int magnitudActual = -1;
int agcActual = -1;
uint8_t agcReferencia = 0;
float anguloVerificacion = 0.0;
bool verificacionValida = false;
float discrepanciaActual = 0.0;
bool divergenciaDetectada = false;
bool imanDesalineado = false;

// --- MPU6050 ---

float anguloTibia = 0.0;
bool tibiaValida = false;
float moduloAcc = 1.0;

// --- Contactos y fases ---

bool contactoTalon = false;
bool contactoPunta = false;

#define BALANCEO 0
#define CONTACTO_TALON 1
#define APOYO_PLANO 2
#define DESPEGUE 3

int fase = BALANCEO;
int fasePrevia = BALANCEO;
unsigned long tEntradaFase = 0;
unsigned long duracionFasePrevia = 0;

// --- Terreno ---

float terrenoEstimado = 0.0;
bool terrenoValido = false;
float acumTerreno = 0.0;
int muestrasPlano = 0;
int muestrasRechazadas = 0;

bool simTerreno = false;
float terrenoInyectado = 0.0;
bool origenSimulado = false;

float serieValores[SERIE_MAX];
int serieN = 0;
int serieIdx = 0;
bool serieActiva = false;
int serieFallos = 0;
unsigned long serieEsperaHasta = 0;

// --- Paso simulado ---

bool pasoActivo = false;
unsigned long tInicioPaso = 0;
unsigned long numeroPaso = 0;
float terrenoPaso = 0.0;
float offsetTerreno = 0.0;
float offsetPrevio = 0.0;
float offsetNuevo = 0.0;
float offsetInicialPaso = 0.0;
bool offsetAplicado = false;
float setpointPaso = 0.0;
float pctPaso = 0.0;
const char* subfasePaso = "inactivo";

// Estadisticas de seguimiento del paso en curso.
long muestrasPaso = 0;
float acumErr2Paso = 0.0;
float errMaxPaso = 0.0;
float pctErrMaxPaso = 0.0;
float velPicoPaso = 0.0;
int pwmPicoPaso = 0;

float caminataValores[SERIE_MAX];
int caminataN = 0;
int caminataIdx = 0;
int caminataReintentos = 0;
int caminataFallos = 0;
bool caminataActiva = false;
unsigned long caminataEsperaHasta = 0;

// --- Clasificadores ---

enum ModoClasificador { CLASIF_HISTERESIS, CLASIF_DIFUSO };
ModoClasificador modoActual = CLASIF_HISTERESIS;
String metodoActivo = "histeresis";
bool modoManual = false;

const float centroClase[N_CLASES] = {-10, -5, 0, 5, 10};
const char* nombreClase[N_CLASES] = {"bajada10", "bajada5", "plano", "subida5", "subida10"};
int claseActual = 2;
int claseEmitida = 2;

// --- Lazo de ajuste ---

float anguloObjetivo = 0.0;
float objetivoPendiente = 0.0;

int pwmAplicado = 0;
int sentidoAplicado = 0;
bool motorActivo = false;
const char* razonCorte = "arranque";
unsigned long frenoHasta = 0;

// Pico retenido entre publicaciones de telemetria. El PWM es un pulso y las
// correcciones duran menos que el periodo de publicacion, asi que el valor
// instantaneo se pierde entre muestras.
int pwmPicoVentana = 0;
int sentidoPicoVentana = 0;

bool bloqueoDetectado = false;
int bloqueosConsecutivos = 0;
unsigned long tBloqueo = 0;

bool autoLiberar = true;
int autoLiberaciones = 0;
bool latchPermanente = false;

bool ajustePendiente = false;
bool ajusteEnCurso = false;
unsigned long tInicioAjuste = 0;
unsigned long tFaseMov = 0;
unsigned long msDiferidos = 0;
unsigned long tDiferidoDesde = 0;

int sentidoActual = 0;
int inversiones = 0;
bool arrancado = false;
long pulsosAlArrancar = 0;
int ticksEnZona = 0;
long pulsosRef = 0;
unsigned long tPulsosRef = 0;

// Metricas del ciclo en curso, para las graficas de Node-RED.
unsigned long latenciaArranqueMs = 0;
bool latenciaTomada = false;
float velPicoCiclo = 0.0;
float sobrepasoCiclo = 0.0;
float errorInicialCiclo = 0.0;
int signoErrorInicial = 0;
int pwmPicoCiclo = 0;

unsigned long numeroCiclo = 0;
unsigned long ciclosDescartados = 0;

bool esperandoAsentamiento = false;
unsigned long tAsentamiento = 0;
bool exitoPendiente = false;
const char* cierrePendiente = "";
unsigned long duracionPendiente = 0;
int inversionesPendiente = 0;

char lineaSerial[64];
int idxLinea = 0;

void cerrarAjuste(bool exito, const char* cierre, unsigned long duracion);
void guardarPosicion();
void inyectarTerreno(float t);
void terminarPaso(const char* cierre);

// --- Tabla de posicion ---

bool tablaCompleta() {
  if (refPulsos[IDX_CERO] != 0) return false;
  for (int i = 0; i < N_REF; i++) {
    if (i != IDX_CERO && refPulsos[i] == 0) return false;
  }
  return true;
}

bool tablaEsMonotona() {
  int signoRef = 0;
  for (int i = 0; i < N_REF - 1; i++) {
    long d = refPulsos[i + 1] - refPulsos[i];
    if (d == 0) return false;
    int sg = (d > 0) ? 1 : -1;
    if (signoRef == 0) signoRef = sg;
    else if (sg != signoRef) return false;
  }
  return true;
}

int puntosFaltantes() {
  int n = 0;
  for (int i = 0; i < N_REF; i++) {
    if (i != IDX_CERO && refPulsos[i] == 0) n++;
  }
  return n;
}

void revalidarTabla() {
  tablaValida = tablaCompleta() && tablaEsMonotona();
}

float anguloDesdePulsos(long p) {
  fueraDeTabla = false;
  if (!tablaValida) return 0.0;

  bool creciente = refPulsos[N_REF - 1] > refPulsos[0];

  if ((creciente && p <= refPulsos[0]) || (!creciente && p >= refPulsos[0])) {
    if (p != refPulsos[0]) fueraDeTabla = true;
    float m = (refAngulos[1] - refAngulos[0]) / (float)(refPulsos[1] - refPulsos[0]);
    return refAngulos[0] + m * (p - refPulsos[0]);
  }

  int u = N_REF - 1;
  if ((creciente && p >= refPulsos[u]) || (!creciente && p <= refPulsos[u])) {
    if (p != refPulsos[u]) fueraDeTabla = true;
    float m = (refAngulos[u] - refAngulos[u - 1]) / (float)(refPulsos[u] - refPulsos[u - 1]);
    return refAngulos[u] + m * (p - refPulsos[u]);
  }

  for (int i = 0; i < N_REF - 1; i++) {
    long a = refPulsos[i], b = refPulsos[i + 1];
    bool dentro = creciente ? (p >= a && p <= b) : (p <= a && p >= b);
    if (dentro) {
      float t = (float)(p - a) / (float)(b - a);
      return refAngulos[i] + t * (refAngulos[i + 1] - refAngulos[i]);
    }
  }
  return 0.0;
}

float pulsosPorGradoLocal() {
  if (!tablaValida) return 1.0;
  long p = pulsosEncoder;
  bool creciente = refPulsos[N_REF - 1] > refPulsos[0];

  for (int i = 0; i < N_REF - 1; i++) {
    long a = refPulsos[i], b = refPulsos[i + 1];
    bool dentro = creciente ? (p >= a && p <= b) : (p <= a && p >= b);
    if (dentro) {
      float dg = refAngulos[i + 1] - refAngulos[i];
      return fabs((b - a) / dg);
    }
  }
  float dg = refAngulos[1] - refAngulos[0];
  return fabs((refPulsos[1] - refPulsos[0]) / dg);
}

float zonaMuertaEfectiva() {
  float porResolucion = PULSOS_ZONA_MUERTA / pulsosPorGradoLocal();
  return (porResolucion > ZONA_MUERTA_CFG) ? porResolucion : ZONA_MUERTA_CFG;
}

long pulsosEnAngulo(float ang) {
  if (!tablaValida) return 0;
  if (ang <= refAngulos[0]) return refPulsos[0];
  if (ang >= refAngulos[N_REF - 1]) return refPulsos[N_REF - 1];

  for (int i = 0; i < N_REF - 1; i++) {
    if (ang >= refAngulos[i] && ang <= refAngulos[i + 1]) {
      float t = (ang - refAngulos[i]) / (refAngulos[i + 1] - refAngulos[i]);
      return refPulsos[i] + (long)(t * (refPulsos[i + 1] - refPulsos[i]));
    }
  }
  return 0;
}

// El lado de salida no se detecta por calado: el mecanismo se libera en vez
// de trabarse. El presupuesto de pulsos es la unica proteccion de ese lado.
long topePulsosSalida() {
  long extremo = pulsosEnAngulo(extremoSalida > 0 ? LIMITE_ANGULO : -LIMITE_ANGULO);
  bool creciente = refPulsos[N_REF - 1] > refPulsos[0];
  bool salidaEsAlza = (extremoSalida > 0) == creciente;
  return salidaEsAlza ? (extremo + MARGEN_PULSOS) : (extremo - MARGEN_PULSOS);
}

bool excedeTopeSalida(long p) {
  if (!tablaValida) return false;
  long tope = topePulsosSalida();
  bool creciente = refPulsos[N_REF - 1] > refPulsos[0];
  bool salidaEsAlza = (extremoSalida > 0) == creciente;
  return salidaEsAlza ? (p >= tope) : (p <= tope);
}

bool sentidoVaHaciaSalida(int sentido) {
  return (extremoSalida > 0) ? (sentido > 0) : (sentido < 0);
}

// --- Persistencia ---

void cargarBrokerIp() {
  prefs.begin(PREFS_NAMESPACE, true);
  String g = prefs.getString(PREFS_KEY_BROKER, brokerIp);
  g.toCharArray(brokerIp, sizeof(brokerIp));
  prefs.end();
}

void guardarBrokerIp(const char* ip) {
  prefs.begin(PREFS_NAMESPACE, false);
  prefs.putString(PREFS_KEY_BROKER, ip);
  prefs.end();
}

void cargarConfiguracion() {
  prefs.begin(PREFS_NAMESPACE, true);
  pwmMin = prefs.getInt(PREFS_KEY_PWMMIN, pwmMin);
  kpControl = prefs.getFloat(PREFS_KEY_KP, kpControl);
  extremoSalida = prefs.getInt(PREFS_KEY_SALIDA, extremoSalida);
  signoTerreno = prefs.getFloat(PREFS_KEY_TERRENO, signoTerreno);
  gananciaObjetivo = prefs.getFloat(PREFS_KEY_GANANCIA, gananciaObjetivo);
  msCicloPaso = prefs.getULong(PREFS_KEY_CICLO, msCicloPaso);
  amplitudPaso = prefs.getFloat(PREFS_KEY_AMPLITUD, amplitudPaso);
  prefs.end();
  dutyJog = pwmMin + 30;
}

void guardarConfiguracion() {
  prefs.begin(PREFS_NAMESPACE, false);
  prefs.putInt(PREFS_KEY_PWMMIN, pwmMin);
  prefs.putFloat(PREFS_KEY_KP, kpControl);
  prefs.putInt(PREFS_KEY_SALIDA, extremoSalida);
  prefs.putFloat(PREFS_KEY_TERRENO, signoTerreno);
  prefs.putFloat(PREFS_KEY_GANANCIA, gananciaObjetivo);
  prefs.putULong(PREFS_KEY_CICLO, msCicloPaso);
  prefs.putFloat(PREFS_KEY_AMPLITUD, amplitudPaso);
  prefs.end();
}

void cargarTabla() {
  prefs.begin(PREFS_NAMESPACE, true);
  size_t leido = prefs.getBytes(PREFS_KEY_TABLA, refPulsos, sizeof(refPulsos));
  prefs.end();
  if (leido != sizeof(refPulsos)) {
    for (int i = 0; i < N_REF; i++) refPulsos[i] = 0;
  }
  revalidarTabla();
}

void guardarTabla() {
  prefs.begin(PREFS_NAMESPACE, false);
  prefs.putBytes(PREFS_KEY_TABLA, refPulsos, sizeof(refPulsos));
  prefs.end();
  revalidarTabla();
}

void marcarMovimiento() {
  prefs.begin(PREFS_NAMESPACE, false);
  prefs.putBool(PREFS_KEY_LIMPIO, false);
  prefs.end();
}

void guardarPosicion() {
  prefs.begin(PREFS_NAMESPACE, false);
  prefs.putFloat(PREFS_KEY_ANGULO, anguloArticulacion);
  prefs.putLong(PREFS_KEY_PULSOS, pulsosEncoder);
  prefs.putBool(PREFS_KEY_LIMPIO, true);
  prefs.end();
}

// --- Puente y freno ---
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
void loop() {
  actualizarContactos();
  atenderFreno();
  atenderEnfriamiento();

  if (millis() - ultimoControl > CONTROL_MS) {
    ultimoControl = millis();

    if (tablaValida) anguloArticulacion = anguloDesdePulsos(pulsosEncoder);
    actualizarVelocidad();
    muestrearMagnitud();

    float ax, ay, az, gx, gy, gz;
    if (leerMPU6050(ax, ay, az, gx, gy, gz)) {
      moduloAcc = sqrt(ax * ax + ay * ay + az * az);
      anguloTibia = anguloTibiaGrados(ax, ay, az);
      tibiaValida = true;
    } else {
      tibiaValida = false;
    }

    actualizarFase();
    acumularTerreno();

    // El paso simulado y el lazo punto a punto son excluyentes.
    if (pasoActivo) {
      ejecutarTrayectoria();
    } else {
      ejecutarAjuste();
      atenderAsentamiento();
      atenderPendienteSimulado();
      atenderSerie();
    }
    atenderCaminata();
  }

  verificarPosicion();

  if (wifiHabilitado) {
    if (!mqttClient.connected()) {
      reconectarMqtt();
    } else {
      mqttClient.loop();
      atenderLog();
      if (telemetriaContinua && millis() - ultimaTelemetria > TELEMETRIA_MS) {
        ultimaTelemetria = millis();
        publicarTelemetria();
      }
    }
  }

  atenderSerial();
}

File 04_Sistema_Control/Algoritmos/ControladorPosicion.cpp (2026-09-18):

#include "ControladorPosicion.h"

ControladorPosicion::ControladorPosicion() {
    _kp = 4.0f;
    _deadband = 65.0f;   // PWM mínimo medido para vencer fricción en rosca M8
    _err_tol = 0.20f;    // Banda de tolerancia para evitar chattering por holgura
}

void ControladorPosicion::inicializar(float kp, float deadband_pwm, float err_tol_deg) {
    _kp = kp;
    _deadband = deadband_pwm;
    _err_tol = err_tol_deg;
}

int16_t ControladorPosicion::calcular(float theta_ref, float theta_real) {
    float error = theta_ref - theta_real;

    // Zona de descanso
    if (fabs(error) <= _err_tol) {
        return 0;
    }

    // Ganancia proporcional escalada a PWM (255 = 12V)
    // Kp en V/deg -> PWM/deg = Kp * (255 / 12) = Kp * 21.25
    float gain_pwm = _kp * 21.25f;
    float u_p = gain_pwm * fabs(error);

    // Compensación directa de fricción de husillo
    float u_total = _deadband + u_p;

    // Saturación a 8 bits
    if (u_total > 255.0f) u_total = 255.0f;

    // Aplicar dirección
    if (error > 0) {
        return (int16_t)u_total;
    } else {
        return -(int16_t)u_total;
    }
}

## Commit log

2026-09-18 chore: inicializar estructura de repositorio y arquitectura de subsistemas
    - Configurar reglas de exclusion en .gitignore para aislar los subsistemas del proyecto
    - Agregar documentacion tecnica general en README.md describiendo especificaciones y arquitectura mecatronica
2026-09-18 feat(mecanico): incorporar modelos CAD, planos de fabricacion y memoria de calculo
    - Modelos CAD parametricos en Autodesk Fusion 360 (.f3d), formatos neutros (.step) y mallas para manufactura aditiva (.stl)
    - Planos tecnicos acotados normalizados en formato PDF con vistas ortogonales, tolerancias y detalles de ensamble
    - Memoria de calculo cinematico de cuadrilatero articulado (+-15 deg sagital) y reporte de barrido cinematico
    [A2_columna_tibial_1.stl, A3_placa_sensor_as5600_1.stl, A3_soporte_tobillo_1.stl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]
2026-09-18 feat(electronico): incorporar esquematicos, distribucion de potencia y conexionado
    - Diagrama de bloques de arquitectura funcional y esquematicos electricos de distribucion de potencia
    - Diagrama de cableado punto a punto y tabla de conexionado de lineas de senal e instrumentacion
    - Dimensionamiento de consumo energetico, lista de materiales (BOM) y documentacion tecnica de componentes
2026-09-18 feat(control): incorporar firmware para ESP32, telemetria MQTT e interfaz Node-RED
    - Firmware para ESP32 con control de lazo cerrado para seguimiento angular (AS5600, HX711, TB6612FNG)
    - Pruebas unitarias de perifericos, escaneo I2C y validacion de actuadores
    - Configuracion de calibracion persistente en NVS, mapa de topicos MQTT y flujos telemetricos en Node-RED
2026-09-18 feat(control, electronica): integrar subsistema 04_Sistema_Control, evidencias de montaje y sincronizacion de metricas
    - Incorporar formalmente el subsistema 04_Sistema_Control (estrategias, algoritmos C++, modelo Simulink .slx, scripts MATLAB y reportes).
    - Integrar fotografias reales de ensamble electronico y cableado en 02_Sistema_Electronico.
    - Sincronizar metricas de validacion de 150 corridas (73/75 en umbrales con histeresis vs 75/75 en logica difusa) en CSV, graficas y reporte PDF.
    - Unificar especificaciones de par del motorreductor GA25-370 (T_nom = 0.15 N*m, T_stall = 0.80 N*m) en memorias tecnicas.
    - Estandarizar mapeo de GPIO y documentacion de firmware en 03_Sistema_Computacion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
    [resultados_150_corridas.csv]
2026-09-30 Referencia
    Biomechanical design of a powered ankle-foot prosthesis
